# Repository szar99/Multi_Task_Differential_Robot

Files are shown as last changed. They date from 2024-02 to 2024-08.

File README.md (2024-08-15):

# Multi-Task Differential Robot
The Multi-Task Differential Robot project focuses on developing a versatile robot equipped with multiple sensors to perform various tasks. Firstly, it can accurately follow a predefined path by utilizing a line following sensor. Secondly, it features obstacle avoidance functionality, leveraging infrared distance sensors to detect and steer clear of objects within its field of view. When encountering an obstacle, the robot adjusts its direction or maneuvers around it, especially in corner scenarios. Lastly, the robot incorporates object tracking capabilities facilitated by the Pixy2 camera. This enables the robot to track and pursue objects, such as a rolling ball on the ground, enhancing its adaptability and usefulness across different applications.

<p align="center">
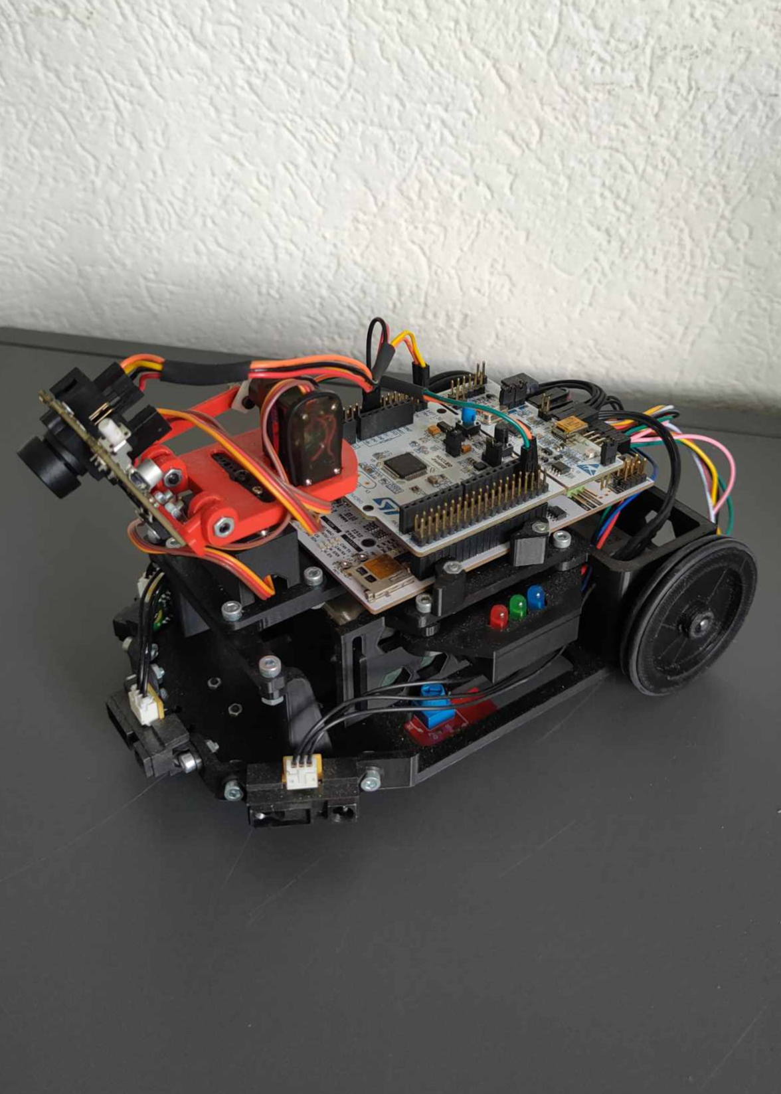
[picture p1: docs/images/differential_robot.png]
Differential robot
     </br>
    <i>Multi-Task Differential Robot</i>
</p>

## Table of Contents
1. [Repository structure](#repository-structure)
2. [Hardware](#hardware)
3. [Prerequisites](#prerequisites)
4. [Kinematics](#kinematics)
5. [Functionalities](#functionalities)
    * [Line follower](#1-line-follower)
    * [Obstacle avoider](#2-obstacle-avoider)
    * [Pixy2 object follower](#3-pixy2-object-follower)
6. [Additions](#additions)
7. [Notes](#notes)

## Repository structure
The ***main.cpp*** file contains all three algorithms. The current algorithm is visible, the rest is commented out.

- ``/docs/cad`` - cad files with division into vechicle frame and gimbal construction for Pixy2. Inside there is a division into different extensions, including print-ready STL files and STEP files. <br>
- ``/docs/documentation`` - folder contains all additional markdown files <br>
- ``/docs/images`` - folder contains all images used in markdown files <br>
- ``/docs/solutions`` - The folder contains the main files of separate three different algorithms. 

## Hardware
Components and sensors employed in the design:
- [Nucleo-F446RE][0]
- 2 x [31:1 Metal Gearmotor 20Dx43L mm 12V CB][1] 
- [SparkFun Line Follower Array][2]
- 4 x [IR distance sensors SHARP 2Y0A21][3] 
- [Pixy2 Cam][4]
- 2 x [Towerpro MG90S servos][5]
- 2 x [Conrad energy NiMH receiver battery packs 6V, 2300mAh][6]
- PES Board
- Jumper wires

All frame parts 3D models are localized in [CAD folder](/docs/cad/)

## Prerequisites
- Mbed Studio
- Libraries:
    - mbed-os 6.17.0
    - eigen
    - pm2_drivers

All the libraries you need are included in the repository. If you use a different design, kinematics, or hardware, you need to change the appropriate variables for the program to run properly. Also, if you are not using a custom PES Board, you need to change pins names that are passed as parameters while objects are defined.

## Running project
In order to run the project you need to import program to Mbed Studio, compile it, and the run on the board. As it was mentioned above, robot has three different functionalities. On the right side of robot there are three diodes, each one of them is sygnalizing the currently used algorithm. Colours are like:
- Pixy follower -> red 
- Obstacle avoider -> green
- Line follower -> blue

After switch on the power source robot will wait for the correct algorithm to be selected by lighting up the LEDs sequentially at five-second intervals. Pressing the **USER** button while the diode of the colour corresponding to the function in question is lit will immediately start the execution of the selected algorithm.

## Kinematics
Comprehensive explanation and description of the kinematics of a differential robot can be found [here](/docs/documentation/kinematics.md).

## Functionalities
As mentioned, the robot has three different functionalities listed below.
### 1. Line follower
The line follower functionality enables the robot to autonomously navigate predefined paths by continuously scanning for contrasting colors or reflective markers with a specialized sensor, making real-time adjustments based on feedback to ensure precise tracking and adherence to the designated route. Details of algorithm you can find [here](/docs/documentation/line_follower.md) <br>
Main file [**Line follower main**](/docs/solutions/Line_follower_main.txt)
### 2. Obstacle avoider
The obstacle avoidance functionality equips the robot with infrared distance sensors to detect objects within its vicinity. When an obstacle is detected, the robot swiftly adjusts its course to avoid collision, either by changing direction or maneuvering around the obstacle. This feature ensures the robot's safe navigation in dynamic environments, preventing potential collisions and ensuring smooth operation. Details of algorithm you can find [here](/docs/documentation/obstacle_avoider.md) <br>
Main file [**Obstacle avoider**](/docs/solutions/Line_follower_main.txt)
### 3. Pixy2 object follower
The Pixy2 object follower functionality allows the robot to seamlessly track and follow designated objects within its view. By leveraging the capabilities of the Pixy2 camera, the robot identifies and locks onto the target object, ensuring precise tracking as it moves. This enables the robot to autonomously follow the object, adjusting its trajectory accordingly for smooth and accurate pursuit. Details of algorithm you can find [here](/docs/documentation/pixy_follower.md) <br>
Main file [**Pixy2 object follower**](/docs/solutions/Line_follower_main.txt)

## Additions
- The files include a map that should be printed on a large scale for the algorithm to run properly: [MAP](docs/Highspeed_2.pdf) 

## Notes:
- Update dependencies after releasing drivers! 

[0]: https://os.mbed.com/platforms/ST-Nucleo-F446RE/
[1]: https://www.pololu.com/product/3487
[2]: https://www.sparkfun.com/products/13582
[3]: https://www.sparkfun.com/products/242
[4]: https://pixycam.com/pixy2/
[5]: https://www.towerpro.com.tw/product/mg90s-3/
[6]: https://www.conrad.ch/de/p/reely-modellbau-akkupack-nimh-6-v-2300-mah-zellen-zahl-5-mignon-aa-side-by-side-jr-buchse-2613252.html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

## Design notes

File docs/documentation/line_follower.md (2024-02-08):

# Line follower
The line follower functionality enables the robot to autonomously navigate along predefined paths by detecting and following lines on the ground. Using a specialized line following sensor, the robot continuously scans the surface for contrasting colors or reflective markers that define the desired path. Real-time adjustments in the robot's movements are made based on the sensor's feedback, ensuring precise tracking and adherence to the designated route.

## Hardware
[Sparkfun Line follower sensor array][1] is used for this functionality.

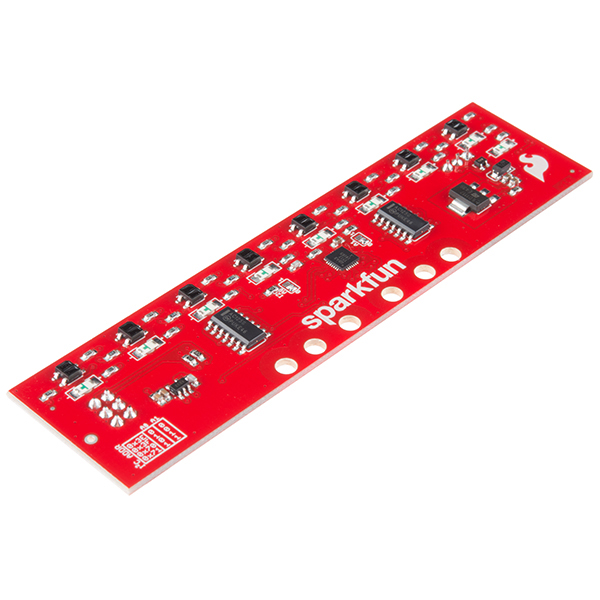
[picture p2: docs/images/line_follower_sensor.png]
Line follower sensor


The sensor incorporates eight diodes for line detection, with each diode's illumination indicating the presence of a line beneath it. Additionally, a calibration knob enables users to adjust detection sensitivity, accommodating variations in substrate and line color shades. More information is available [here][2].

For sensor communication, SPI technology is utilized, which relies on two data pins and a clock (more information [here][3]). To power the sensor, a voltage of around 5V is required.

In the described robot, the following pins are utilized:
- Data **PB_9**
- Clock **PB_8**

**NOTE:** [Nucleo-F446RE pinmap][4] 

## Software
The following is a description of the software used to perform the task in the form of line tracking. 
### Main
The algorithm calculating the appropriate values of wheel speeds is built inside the driver, so from the main file it is necessary to define the appropriate variables and declare the appropriate objects. The software code must contain:
- DC motor object - manual for DC motors can be found here 
<!-- TODO add link -->
- Line follower object - manual for line follower driver can be [here](#line-follower-driver)

The line follower's ``main`` file can be found [here](../solutions/Line_follower_main.txt). The description below refers to this file and contains an explanation of how the algorithm inside is constructed.

#### State machine

1. Initial State (INITIAL):
- In this state, all systems are enabled, and the robot prepares for operation.
- If the robot is moving (determined by the condition `move == true`), it transitions to the FOLLOW state to start following the line.
- If the robot is not moving (determined by the condition `move == false`), it transitions to the SLEEP state to wait for a signal to start moving.

2. Follow State (FOLLOW):
- In this state, the robot actively follows the line using the line-following algorithm.
- The robot's motor speeds are adjusted based on the line-following algorithm's outputs.
- If the robot stops moving (determined by the condition `move == false`), it transitions to the SLEEP state to wait for a signal to start moving again.

3. Sleep State (SLEEP):
- In this state, the robot stops its motors and waits for a signal to start moving.
- If the robot detects movement (determined by the condition `move == true`), it transitions to the FOLLOW state to resume line-following.

#### Possible adjustments
The algorithm is programmed to have the robot move for a specific period after losing the line, and then stop. To achieve this, functionality has been implemented to determine the stopping time for the robot based on a predefined duration. The process unfolds as follows:

1. Time Definition: The parameter `stop_time` defines the duration (in seconds) for which the robot should move after losing the line before coming to a complete stop.

2. Conversion to Iterations: This time is converted into an equivalent number of iterations (`stop_time_iteration`) based on the main task period. For instance, if the main task period is 20 milliseconds and `stop_time` is set to 1 second, then `stop_time_iteration` would be calculated as 1000 ms / 20 ms = 50 iterations.

3. Counter Incrementation: Upon losing the line, a counter (`i`) is incremented. This counter keeps track of the number of iterations since the robot last detected the line.

4. Checking Counter Against Threshold: If the counter (`i`) exceeds the predetermined number of iterations (`stop_time_iteration`), it indicates that the specified time has elapsed since the robot lost the line.

5. Setting the `move` Variable: Once the counter exceeds `stop_time_iteration`, the `move` variable is set to `false`. This action causes the robot to stop moving entirely.

By adjusting the `stop_time` parameter, users can control the duration for which the robot continues to move after losing the line. Increasing `stop_time` extends the movement duration, while decreasing it shortens the interval before the robot comes to a stop.

### Line follower driver
Line follower driver is used to calculate wheel speed based on sensor indications and robot geometry, as well as other settings declared by the user.

#### Constructor
When declaring a function, the following variables must be defined (in **SI** units if applicable):
- SDA pin - used for data transfer in SPI standard
- SCL pin - used for clock synchronization
- bar_dist - distance of diodes from wheel axes
- d_wheel - wheel diameter
- L_wheel - wheelbase
- max_motor_vel_rps - maximum engine speed given in revolutions per second

The remaining values are defined by default, but there is a possibility to change some of the parameters, as described below the description of the internal algorithm operation

**NOTE:** The velocity values provided as input are originally expressed in revolutions per second. However, within the driver, these values are converted into radians per second for calculation purposes. Once the calculation is completed in this unit, it is then converted back into revolutions per second. This conversion allows for the use of a unit directly compatible with the DC motor object.

#### Thread algorithm description
The `followLine` function is a thread task method responsible for controlling the robot to follow a line based on sensor readings.

1. Thread Execution: The `followLine` method runs continuously in a thread loop. It waits for a thread flag to be set before executing, indicating that it should perform its task.

2. Sensor Reading: Inside the loop, the method checks if any LEDs on the sensor bar are active. If any LEDs are active, it calculates the average angle of the detected line segments relative to the robot's orientation. This angle is stored in `m_sensor_bar_avgAngleRad`.

3. Control Calculation:
- The maximum wheel velocity in radians per second (`m_max_wheel_vel_rads`) is calculated based on the maximum wheel velocity (`m_max_wheel_vel`).
- The rotational velocity (`m_robot_coord(1)`) is determined using a control function `ang_cntrl_fcn`, which adjusts the robot's orientation to align with the detected line.
- The translational velocity (`m_robot_coord(0)`) is determined using another control function `vel_cntrl_v2_fcn`, which calculates the robot's forward velocity based on the rotational velocity and geometric parameters.
- The robot's wheel speeds are calculated using the inverse transformation matrix `m_Cwheel2robot`.

4. Wheel Velocity Conversion: The calculated wheel speeds are converted from radians per second to revolutions per second (`m_right_wheel_velocity` and `m_left_wheel_velocity`).

5. Thread Flag Signaling: After completing its task, the method waits for the next iteration by waiting for the thread flag to be set again.

#### Angular velocity controller
The `ang_cntrl_fcn` function is responsible for calculating the angular velocity of the robot based on the detected angle of the line relative to the robot's orientation. This function uses proportional and non-linear control to calculate the velocity based on mentioned angle.

1. Input Parameters:
- `Kp`: Proportional gain parameter for angular control.
- `Kp_nl`: Non-linear gain parameter for angular control.
- `angle`: The angle of the detected line relative to the robot's orientation.

2. Calculation:
- If the angle is positive (`angle > 0`), the function calculates the angular velocity (`retval`) using the formula:
    ```
    retval = Kp * angle + Kp_nl * angle * angle
    ```
    This formula applies proportional control (`Kp * angle`) along with a non-linear correction term (`Kp_nl * angle * angle`).
- If the angle is zero or negative (`angle <= 0`), the function calculates the angular velocity (`retval`) using a similar formula but with a negative sign for the non-linear term:
    ```
    retval = Kp * angle - Kp_nl * angle * angle
    ```
3. Output:
- The function returns the calculated angular velocity (`retval`).

#### Linear velocity controller
The `vel_cntrl_v2_fcn` function calculates the linear velocity of the robot based on its angular velocity and geometric parameters. The function ensures that one of the robot's wheels always turns at maximum velocity while the other adjusts its speed to maintain the desired angular velocity.

1. Input Parameters:
- `wheel_speed_max`: Maximum wheel speed in radians per second.
- `b`: Geometric parameter related to the distance between the wheels .
- `robot_omega`: Angular velocity of the robot.
- `Cwheel2robot`: Transformation matrix from wheel to robot coordinates.

2. Calculation:
- If `robot_omega` is positive, it assigns the maximum wheel speed to the first wheel and calculates the speed for the second wheel by subtracting `2 * b * robot_omega` from the maximum speed.
- If `robot_omega` is negative or zero, it assigns the maximum wheel speed to the second wheel and calculates the speed for the first wheel by adding `2 * b * robot_omega` to the maximum speed.
- The function then calculates the robot's coordinate velocities by multiplying the transformation matrix `Cwheel2robot` by the wheel speeds.
- Finally, it returns the linear velocity of the robot, which corresponds to the velocity along the x-axis in the robot's coordinate system.

3. Output:
- The function returns the calculated linear velocity of the robot.

#### Parametres adjustment
The LineFollower class provides functionality to dynamically adjust key parameters:

1. Proportional Gain (Kp) and Non-linear Gain (Kp_nl):
- Function: `void setRotationalVelocityGain(float Kp, float Kp_nl)`
- Parameters: `Kp` and `Kp_nl`
- Description: These parameters influence the proportional and non-linear correction in the robot's angular velocity control, allowing users to fine-tune the response to deviations from the desired line angle.

2. Maximum Wheel Velocity:
- Function: `void setMaxWheelVelocity(float max_wheel_vel)`
- Parameter: `max_wheel_vel`
- Description: This parameter limits the maximum wheel velocity (argument in rotations per second), indirectly affecting the robot's linear and angular velocities. Users can adjust this limit to optimize performance based on environmental conditions and specific requirements.

<!-- Links: -->
[1]: https://www.sparkfun.com/products/13582
[2]: https://learn.sparkfun.com/tutorials/sparkfun-line-follower-array-hookup-guide
[3]: https://learn.sparkfun.com/tutorials/serial-peripheral-interface-spi/all
[4]: https://os.mbed.com/platforms/ST-Nucleo-F446RE/

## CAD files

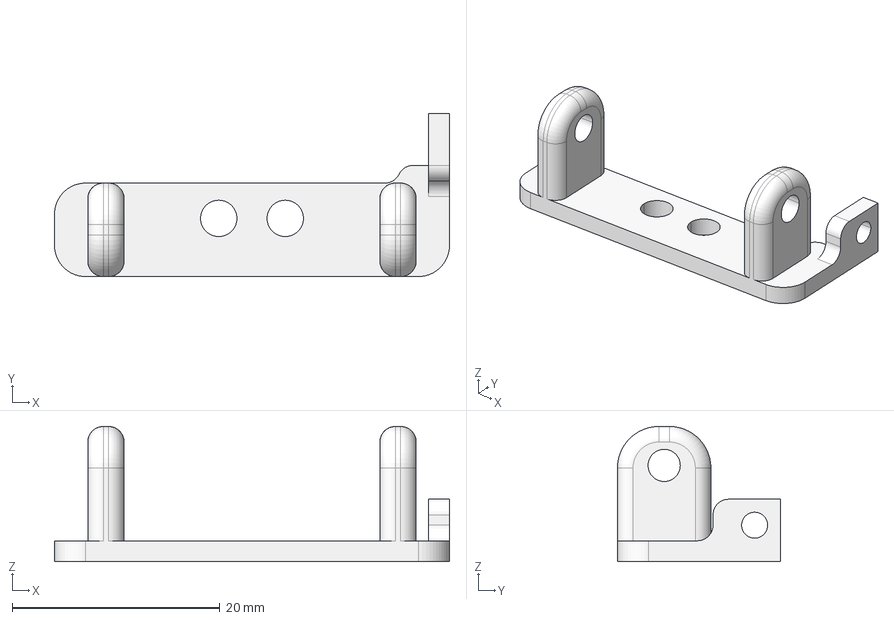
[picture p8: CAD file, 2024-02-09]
docs/cad/pixy2_gimbal/STEP/SDR_mipantiltPixyCam2.stp
38.0 x 15.7 x 13.0 mm

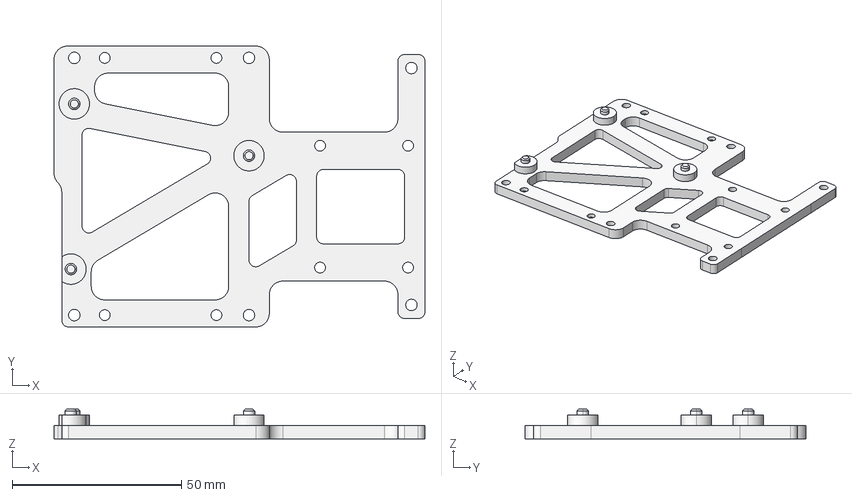
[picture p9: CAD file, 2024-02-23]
docs/cad/robot_frame/STEP/SDR_PCB_BASE_WITH_KNOBS.stp
109.6 x 83.0 x 8.80 mm

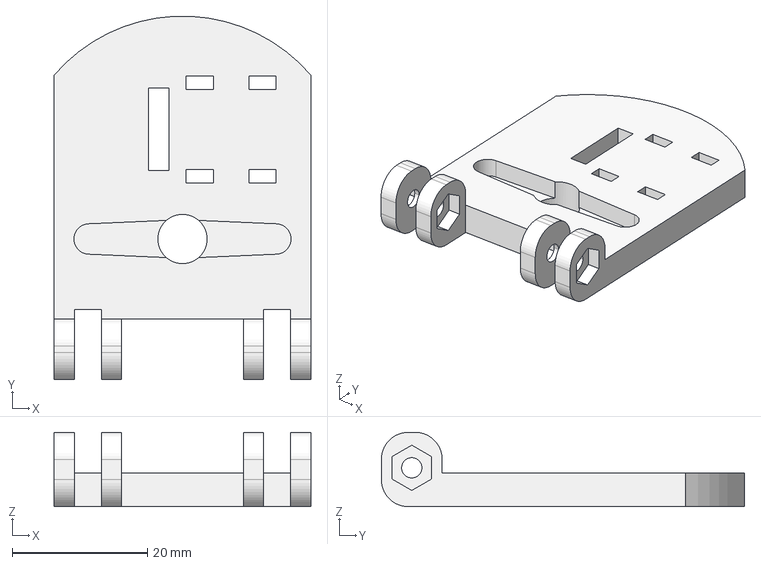
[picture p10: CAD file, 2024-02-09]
docs/cad/pixy2_gimbal/STEP/SDR_mipantiltPixyTilt2.stp
38.0 x 53.7 x 11.0 mm

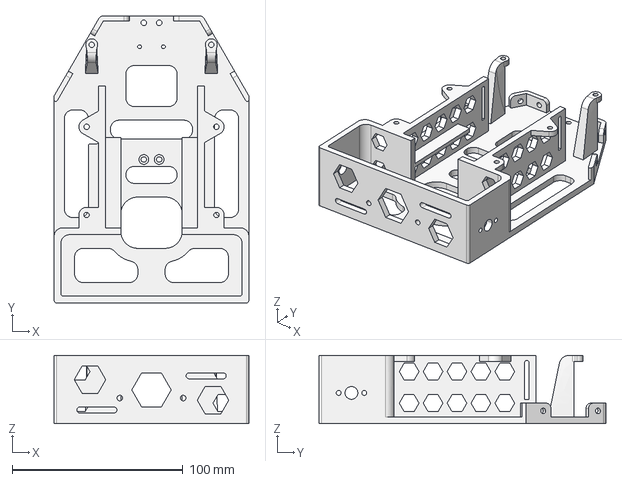
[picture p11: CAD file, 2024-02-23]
docs/cad/robot_frame/STEP/SDR_ROBOT_FRAME.stp
114.0 x 168.0 x 40.0 mm

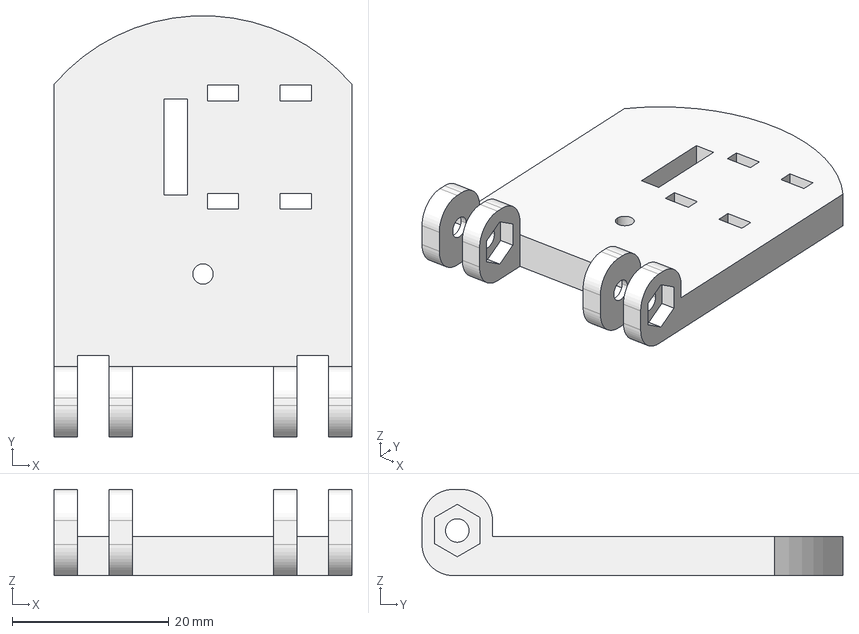
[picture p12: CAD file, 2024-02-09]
docs/cad/pixy2_gimbal/STEP/SDR_mipantiltPixyTilt2_WaveShare.stp
38.0 x 53.7 x 11.0 mm

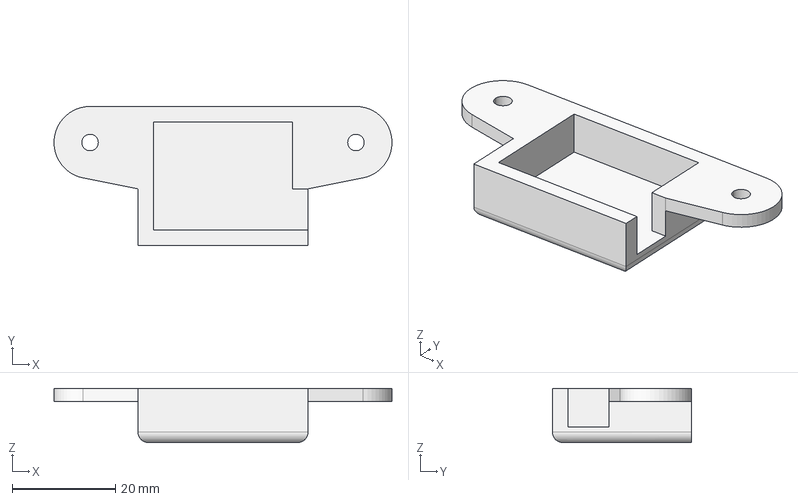
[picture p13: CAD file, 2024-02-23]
docs/cad/robot_frame/STEP/SDR_LED_CASE_DOWN.stp
65.6 x 27.0 x 10.5 mm

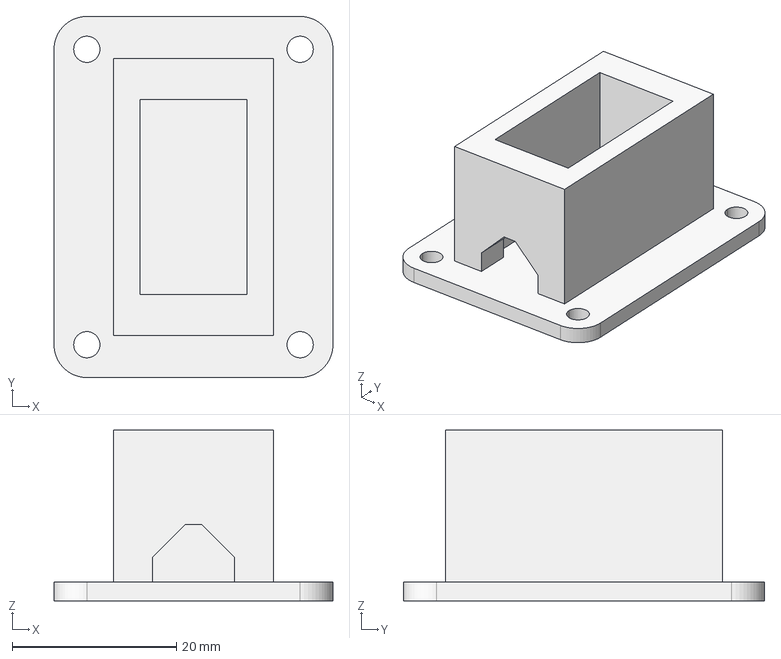
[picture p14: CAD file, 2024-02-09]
docs/cad/pixy2_gimbal/STEP/SDR_mipantiltPixyPan.stp
34.0 x 44.0 x 20.8 mm

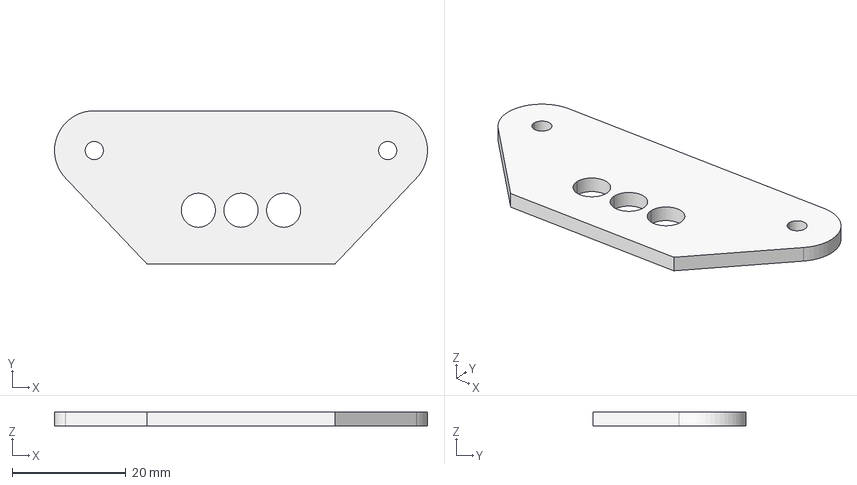
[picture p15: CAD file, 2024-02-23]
docs/cad/robot_frame/STEP/SDR_LED_CASE_TOP.stp
65.6 x 27.0 x 2.50 mm

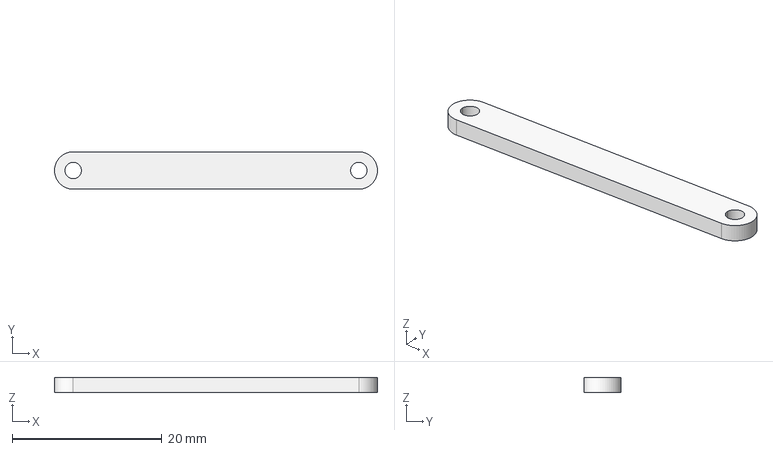
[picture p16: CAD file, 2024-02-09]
docs/cad/pixy2_gimbal/STEP/SDR_mipantiltPixyPush2.stp
43.1 x 5.00 x 2.00 mm

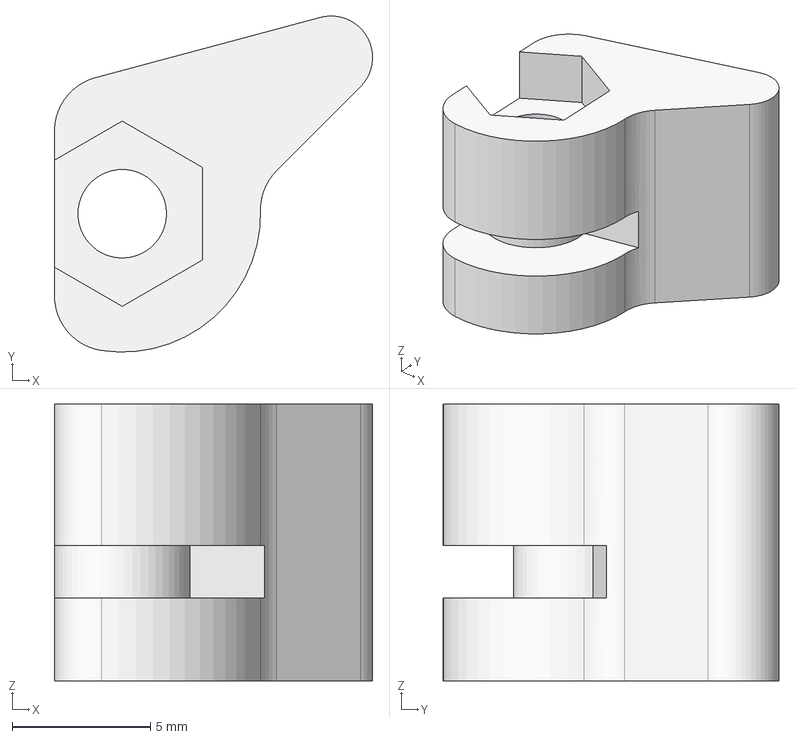
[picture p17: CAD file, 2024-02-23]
docs/cad/robot_frame/STEP/SDR_PCB_MOUNT_KNOB.stp
11.5 x 12.1 x 10.0 mm

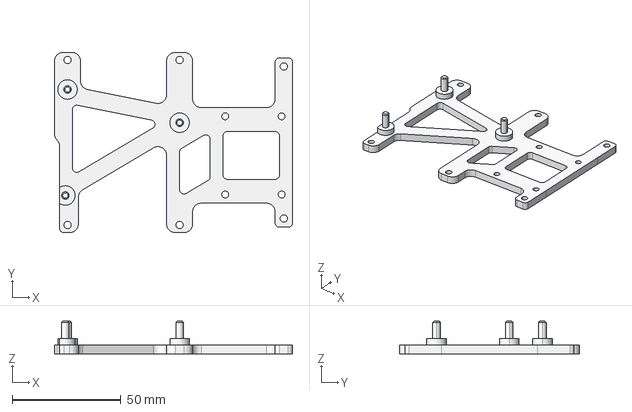
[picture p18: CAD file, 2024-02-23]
docs/cad/robot_frame/STEP/SDR_PCB_BASE_LONG_PINS.stp
109.6 x 83.0 x 15.0 mm

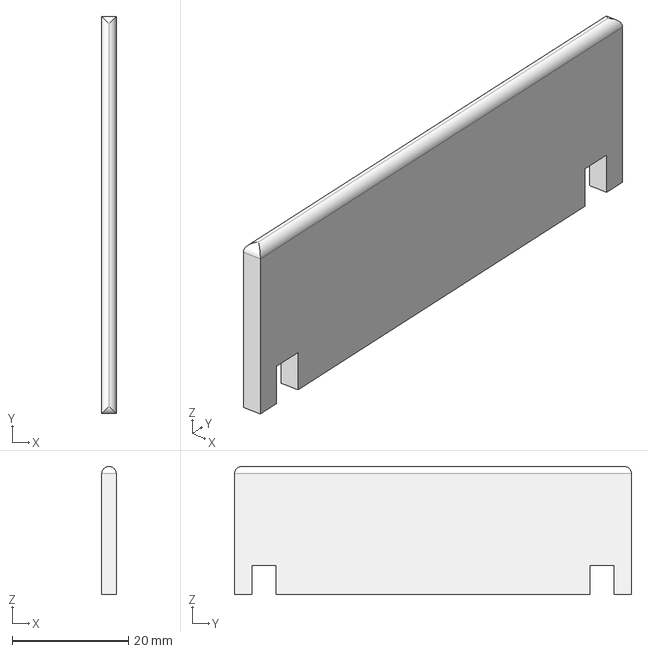
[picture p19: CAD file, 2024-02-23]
docs/cad/robot_frame/STEP/SDR_BATTERY_BLOCK.stp
2.50 x 68.2 x 22.0 mm

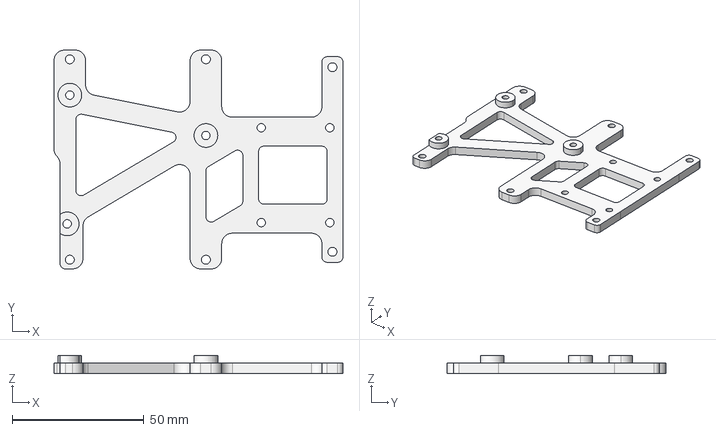
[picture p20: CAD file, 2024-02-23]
docs/cad/robot_frame/STEP/SDR_PCB_BASE_SCREWS.stp
109.6 x 83.0 x 7.00 mm

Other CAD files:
docs/cad/pixy2_gimbal/STEP/SDR_mipantiltPixyTilt2_TowerPro.stp
docs/cad/pixy2_gimbal/STL/SDR_mipantiltPixyCam2.stl
docs/cad/pixy2_gimbal/STL/SDR_mipantiltPixyPan.stl
docs/cad/pixy2_gimbal/STL/SDR_mipantiltPixyPush2.stl
docs/cad/pixy2_gimbal/STL/SDR_mipantiltPixyTilt2.stl
docs/cad/pixy2_gimbal/STL/SDR_mipantiltPixyTilt2_TowerPro.stl
docs/cad/pixy2_gimbal/STL/SDR_mipantiltPixyTilt2_WaveShare.stl
docs/cad/robot_frame/STL/SDR_BATTERY_BLOCK.stl
docs/cad/robot_frame/STL/SDR_LED_CASE_DOWN.stl
docs/cad/robot_frame/STL/SDR_LED_CASE_TOP.stl
docs/cad/robot_frame/STL/SDR_PCB_BASE_LONG_PINS.stl
docs/cad/robot_frame/STL/SDR_PCB_BASE_SCREWS.stl
docs/cad/robot_frame/STL/SDR_PCB_BASE_WITH_KNOBS.stl
docs/cad/robot_frame/STL/SDR_PCB_MOUNT_KNOB.stl
docs/cad/robot_frame/STL/SDR_ROBOT_FRAME.stl

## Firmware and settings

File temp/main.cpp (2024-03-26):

#include <mbed.h>
#include <math.h>

#include "pm2_drivers/DebounceIn.h"
#include "pm2_drivers/Servo.h"
#include "pm2_drivers/EncoderCounter.h"
#include "pm2_drivers/DCMotor.h"
#include "pm2_drivers/UltrasonicSensor.h"
#include "pm2_drivers/IMU.h"
#include "pm2_drivers/SensorBar.h"
#include "pm2_drivers/PESBoardPinMap.h"
#include "eigen/Dense.h"
#include "pm2_drivers/LineFollower.h"
#include "pm2_drivers/PixyCam2.h"

#define M_PI 3.14159265358979323846  // number pi

// logical variable main task
bool do_execute_main_task = false;

// user button on nucleo board
Timer user_button_timer;            
DebounceIn user_button(USER_BUTTON);

// Sensor evaluation function
float ir_sensor_compensation(float _ir_distance_mV);

// Controling functions
// obstacle avoider motion controllers 
float rot_vel_from_radius_fcn(const float& wheel_speed_max, const float& r_wheel, const float& L_wheel ,const float& R_turn);
float turn_angle_limit_fcn(const float& R_turn, const float& r_wheel, const float& L_wheel, const float& angle);
// Pixy object position to velocity 
float pixy_following_x_fcn(const float& x, const float& x_threshold, const float& Kx);
float pixy_following_y_fcn(const float& y, const float& y_t, const float& Ky, const float& y_boundary);
// linear velocity calculation algorithm
float vel_cntrl_v2_fcn(const float& wheel_speed_max, const float& b, const float& robot_omega, const Eigen::Matrix2f& Cwheel2robot);

int main()
{
    // Robot states - three functionalities
    enum RobotState {
        INIT,
        PIXY_FOLLOWER,
        OBST_AVOIDER,
        LINE_FOLLOWER
    } robot_state = RobotState::INIT;

    bool pixy_follower = false;
    bool obst_avoider = false;
    bool line_follower = false;

    // while loop gets executed every main_task_period_ms milliseconds
    const int main_task_period_ms = 30;   // define main task period time in ms
    Timer main_task_timer;
    Timer task_selection_timer;  

    // PIXY FOLLOWER STATE MACHINE WITH 3 STATES:
    // initial - to enable motors
    // follow - to follow object if it is in sight
    // sleep - to do nothing if it is in sight
    enum RobotStatePixyFollower {
        INITIAL_P,
        FOLLOW_P,
        SLEEP_P
    } robot_state_pixy_follower = RobotStatePixyFollower::INITIAL_P;

    // OBSTACLE AVOIDER STATE MACHINE WITH 8 STATES:
    // initial - to enable motors
    // forward - to move forward
    // backward - to move backward and make turn in case of facing obstacle by front sensor
    // backward_corner_left - to move backward and make tight turn in case of facing obstacle by front and left sensor
    // backward_corner_right - to move backward and make tight turn in case of facing obstacle by front and right sensor
    // right - to turn right in case of facing obstacle from left side
    // left - to turn left in case of facing obstacle from right side
    // sleep - to do nothing
    enum RobotStateObstAvoider {
        INITIAL_O,
        FORWARD_O,
        BACKWARD_O,
        BACKWARD_CORNER_LEFT_O,
        BACKWARD_CORNER_RIGHT_O,
        RIGHT_O,
        LEFT_O,
        SLEEP_O,
    } robot_state_obst_avoider = RobotStateObstAvoider::INITIAL_O;

    // LINE FOLLOWER STATE MACHINE WITH 3 STATES:
    // initial - to enable all systems
    // follow - to follow the line
    // sleep - to wait for the signal from the environment (e.g. line detection)
    enum RobotStateLineFollower {
        INITIAL_L,
        FOLLOW_L,
        SLEEP_L,
    } robot_state_line_follower = RobotStateLineFollower::INITIAL_L;

    // led on nucleo board
    DigitalOut user_led(USER_LED);

    DigitalOut led_red(PC_8);
    DigitalOut led_green(PB_2);
    DigitalOut led_blue(PB_12);

    // MOTORS DECLARATIONS
    // Digital out object for enabling motors
    DigitalOut enable_motors(PB_ENABLE_DCMOTORS);

    // In the robot there will be used 31:1 Metal Gearmotor 20Dx44L mm 12V CB
    // Define variables and create DC motor objects
    const float voltage_max = 12.0f;
    const float gear_ratio = 78.125f; 
    const float kn = 180.0f / 12.0f; //motor constant rpm / V
    const float velocity_max = kn * voltage_max / 60.0f; // Max velocity that can be reached
    DCMotor motor_M1(PB_PWM_M1, PB_ENC_A_M1, PB_ENC_B_M1, gear_ratio, kn, voltage_max); //RIGHT
    motor_M1.setEnableMotionPlanner(true);
    motor_M1.setMaxVelocity(motor_M1.getMaxPhysicalVelocity()/2.0f); //right
    DCMotor motor_M2(PB_PWM_M2, PB_ENC_A_M2, PB_ENC_B_M2, gear_ratio, kn, voltage_max); //LEFT
    motor_M2.setEnableMotionPlanner(true);
    motor_M2.setMaxVelocity(motor_M2.getMaxPhysicalVelocity()/2.0f); //left
    const float wheel_speed_max_rads = 2.0f * M_PI * motor_M1.getMaxVelocity(); 

    // ROBOT KINEMATICS AND GEOMETRY
    const float d_wheel = 0.0564f;        // wheel diameter
    const float r_wheel = d_wheel / 2.0f; // wheel radius
    const float L_wheel = 0.13f;         // distance from wheel to wheel
    Eigen::Matrix2f Cwheel2robot; // transform wheel to robot
    //Eigen::Matrix2f Crobot2wheel; // transform robot to wheel
    Cwheel2robot <<  r_wheel / 2.0f   ,  r_wheel / 2.0f   ,
                     r_wheel / L_wheel, -r_wheel / L_wheel;
    //Crobot2wheel << 1.0f / r_wheel,  L_wheel / (2.0f * r_wheel),
    //                1.0f / r_wheel, -L_wheel / (2.0f * r_wheel);
    Eigen::Vector2f robot_coord;  // contains v and w (robot translational and rotational velocities)
    Eigen::Vector2f wheel_speed;  // w1 w2 (wheel speed)
    robot_coord.setZero();
    wheel_speed.setZero();

    const static float b = L_wheel / (2.0f * r_wheel);

    // sensor data evalution
    const float bar_dist = 0.083f;

    // PIXY FOLLOWER OBJECTS AND VARIABLES
    PixyCam2 pixy(PC_10, PC_11, 230400);

    // Evaluation of velocity controller
    float y;
    float x;
    const float y_threshold = 800.0f;
    const float y_boundary = 500.0f;
    const float x_threshold = 500.0f;
    const float Kx = 1.0f / 200.0f;
    const float Ky = 1.0f / 200.0f;
    static float wheel_speed_eval;
    bool isNewMessagePixy = false;

    // OBSTACLE AVOIDER OBJECTS AND VARIABLES
    // condition for state machine that will stop the robot 1 seconds after leaving the line (CAN BE CHANGED)
    bool move = false;
    const static float stop_time = 1.0f; //seconds
    const static int stop_time_iteration = stop_time * 1000 / main_task_period_ms;
    static int i = stop_time_iteration + 1;

    const float R_turn_forward = L_wheel;
    const float R_turn_backward = L_wheel;
    const float R_turn_corner_backward = L_wheel / 2.0f;  

    const float alfa_backward = 90.0f;
    const float alfa_backward_corner = 135.0f;
    const float wheel_rounds_backward = turn_angle_limit_fcn(R_turn_backward, r_wheel, L_wheel, alfa_backward);
    const float wheel_rounds_backward_corner = turn_angle_limit_fcn(R_turn_corner_backward, r_wheel, L_wheel, alfa_backward_corner);

    static float init_rotation;
    static float actual_rotation;
    static bool isFirst = false;

    //IR range sensors:
    AnalogIn ir_analog_in_left(PC_2);
    AnalogIn ir_analog_in_right(PC_5);
    AnalogIn ir_analog_in_front(PC_3);
    AnalogIn ir_analog_in_back(PB_1);

    static float ir_distance_left_cm = 0.0f;
    static float ir_distance_right_cm = 0.0f;
    static float ir_distance_front_cm = 0.0f;
    static float ir_distance_back_cm = 0.0f;

    // Distance threshold for sensors
    const float threshold = 13.0f;

    // LINE FOLLOWER OBJECTS AND VARIABLES
    LineFollower lineFollower(PB_9, PB_8, bar_dist, d_wheel, L_wheel, velocity_max/2.0f);

    // MAIN THREAD FUNCTION
    // Timer to measure task execution time
    main_task_timer.start();

    while (true) {
        main_task_timer.reset();
        task_selection_timer.start();
        
        switch (robot_state) {
            case RobotState::INIT: {
                int task_selection_time_ms = std::chrono::duration_cast<std::chrono::milliseconds>(task_selection_timer.elapsed_time()).count();
                if (task_selection_time_ms >= 1000 && task_selection_time_ms < 5000){
                    pixy_follower = true;
                    led_red = 1;
                }
                else if ((task_selection_time_ms >= 5000 && task_selection_time_ms < 10000)) {
                    pixy_follower = false;
                    obst_avoider = true;
                    led_red = 0;
                    led_green = 1;
                }
                else if ((task_selection_time_ms >= 10000 && task_selection_time_ms < 15000)) {
                    obst_avoider = false;
                    line_follower = true;
                    led_green = 0;
                    led_blue = 1;
                } 
                else if (task_selection_time_ms >= 15000) {
                    led_blue = 0;
                    line_follower = false;
                    task_selection_timer.reset();
                }
                
                if (pixy_follower && user_button == 0){
                    robot_state = PIXY_FOLLOWER;
                }
                else if (obst_avoider && user_button == 0) {
                    robot_state = OBST_AVOIDER;
                }
                else if (line_follower && user_button == 0) {
                    robot_state = LINE_FOLLOWER;
                } else {
                    break;
                }

                break;
            }
            case RobotState::PIXY_FOLLOWER: {
                printf("PIXYFOLLOWER \n");
                y = (float)pixy.getTiltCommand();
                x = (float)pixy.getPanCommand();
                // state machine
                switch (robot_state_pixy_follower) {
                    case RobotStatePixyFollower::INITIAL_P:
                        enable_motors = 1;
                        pixy.followerEnable(true);
                        isNewMessagePixy = pixy.checkForNewMessage();
                        if (isNewMessagePixy == true) {
                            robot_state_pixy_follower = RobotStatePixyFollower::FOLLOW_P;
                        } else {
                            robot_state_pixy_follower = RobotStatePixyFollower::SLEEP_P;
                        }
                        break;

                    case RobotStatePixyFollower::FOLLOW_P:
                        robot_coord(1) = pixy_following_x_fcn(x, x_threshold, Kx);
                        wheel_speed_eval = pixy_following_y_fcn(y, y_threshold, Ky, y_boundary);
                        robot_coord(0) = vel_cntrl_v2_fcn(wheel_speed_eval, b, robot_coord(1), Cwheel2robot);
                        // transform robot coordinates to wheel speed
                        wheel_speed = Cwheel2robot.inverse() * robot_coord;

                        motor_M1.setVelocity(wheel_speed(0) / (2.0f * M_PI));
                        motor_M2.setVelocity(wheel_speed(1) / (2.0f * M_PI));
                        isNewMessagePixy = pixy.checkForNewMessage();

                        if (isNewMessagePixy == false) {
                            robot_state_pixy_follower = RobotStatePixyFollower::SLEEP_P;
                        }
                        break;
                    case RobotStatePixyFollower::SLEEP_P:
                        motor_M1.setVelocity(0.0f);
                        motor_M2.setVelocity(0.0f);
                        pixy.followerEnable(false);
                        pixy.setServos(500, 500);
                        isNewMessagePixy = pixy.checkForNewMessage();

                        if (isNewMessagePixy == true) {
                            pixy.followerEnable(true);
                            robot_state_pixy_follower = RobotStatePixyFollower::FOLLOW_P;
                        }
                        break;
                    default:
                        break; // do nothing
                }
                break;
            }
            case RobotState::OBST_AVOIDER: {
                printf("OBSTACLEAVOIDER \n");
                //IR sensors distances
                ir_distance_left_cm = ir_sensor_compensation(1.0e3f * ir_analog_in_left.read() * 3.3f);
                ir_distance_right_cm = ir_sensor_compensation(1.0e3f * ir_analog_in_right.read() * 3.3f);
                ir_distance_front_cm = ir_sensor_compensation(1.0e3f * ir_analog_in_front.read() * 3.3f);
                ir_distance_back_cm = ir_sensor_compensation(1.0e3f * ir_analog_in_back.read() * 3.3f);

                // transform robot coordinates to wheel speed
                wheel_speed = Cwheel2robot.inverse() * robot_coord;
                
                switch (robot_state_obst_avoider) {
                    case RobotStateObstAvoider::INITIAL_O:
                        enable_motors = 1;
                        robot_state_obst_avoider = RobotStateObstAvoider::FORWARD_O;
                        break;

                    case RobotStateObstAvoider::FORWARD_O:
                        robot_coord(1) = 0;
                        robot_coord(0) = vel_cntrl_v2_fcn(wheel_speed_max_rads, b, robot_coord(1), Cwheel2robot);
                        wheel_speed = Cwheel2robot.inverse() * robot_coord;

                        motor_M1.setVelocity(wheel_speed(0) / (2.0f * M_PI));
                        motor_M2.setVelocity(wheel_speed(1) / (2.0f * M_PI));
                        
                        if (ir_distance_front_cm < threshold & ir_distance_right_cm > threshold & ir_distance_left_cm > threshold) {
                            isFirst = true;
                            robot_state_obst_avoider = RobotStateObstAvoider::BACKWARD_O;
                        }
                        else if (ir_distance_left_cm < threshold) {
                            robot_state_obst_avoider = RobotStateObstAvoider::RIGHT_O;
                        }
                        else if (ir_distance_right_cm < threshold) {
                            robot_state_obst_avoider = RobotStateObstAvoider::LEFT_O;
                        }
                        else if (ir_distance_front_cm < threshold & ir_distance_right_cm < threshold) {
                            isFirst = true;
                            robot_state_obst_avoider = RobotStateObstAvoider::BACKWARD_CORNER_RIGHT_O;
                        }
                        else if (ir_distance_front_cm < threshold & ir_distance_left_cm < threshold) {
                            isFirst = true;
                            robot_state_obst_avoider = RobotStateObstAvoider::BACKWARD_CORNER_LEFT_O;
                        }
                        break;

                    case RobotStateObstAvoider::BACKWARD_O: // add routine to turn with bigger radius and go forward after 45 degrees turn
                        if (isFirst) {
                            if (ir_distance_left_cm < ir_distance_right_cm) {
                                init_rotation = motor_M1.getRotation();
                                actual_rotation = motor_M1.getRotation();
                                robot_coord(1) = - rot_vel_from_radius_fcn(wheel_speed_max_rads, r_wheel, L_wheel, R_turn_backward);
                            }
                            else {
                                init_rotation = motor_M2.getRotation();
                                actual_rotation = motor_M2.getRotation();
                                robot_coord(1) = rot_vel_from_radius_fcn(wheel_speed_max_rads, r_wheel, L_wheel, R_turn_backward);
                            } 
                        } 
                        else {
                            if (ir_distance_left_cm < ir_distance_right_cm) {
                                actual_rotation = motor_M1.getRotation();
                            }
                            else {
                                actual_rotation = motor_M2.getRotation();
                            }
                        }
                        isFirst = false;
                        robot_coord(0) = vel_cntrl_v2_fcn(-wheel_speed_max_rads, b, robot_coord(1), Cwheel2robot);
                        wheel_speed = Cwheel2robot.inverse() * robot_coord;
                        motor_M1.setVelocity(wheel_speed(0) / (2.0f * M_PI));
                        motor_M2.setVelocity(wheel_speed(1) / (2.0f * M_PI));
                        

                        if (ir_distance_back_cm < threshold | actual_rotation < (init_rotation - wheel_rounds_backward)) {
                            init_rotation = 0.0f;
                            actual_rotation = 0.0f;
                            robot_state_obst_avoider = RobotStateObstAvoider::FORWARD_O;
                        }
                        break;

                    case RobotStateObstAvoider::RIGHT_O:
                        robot_coord(1) = - rot_vel_from_radius_fcn(wheel_speed_max_rads, r_wheel, L_wheel, R_turn_forward);
                        robot_coord(0) = vel_cntrl_v2_fcn(wheel_speed_max_rads, b, robot_coord(1), Cwheel2robot);
                        motor_M1.setVelocity(wheel_speed(0) / (2.0f * M_PI));
                        motor_M2.setVelocity(wheel_speed(1) / (2.0f * M_PI));

                        if  (ir_distance_left_cm > threshold) {
                            robot_state_obst_avoider = RobotStateObstAvoider::FORWARD_O;
                        }
                        else if (ir_distance_front_cm < threshold & ir_distance_left_cm < threshold) {
                            isFirst = true;
                            robot_state_obst_avoider = RobotStateObstAvoider::BACKWARD_CORNER_LEFT_O;
                        }
                        break;

                    case RobotStateObstAvoider::LEFT_O:
                        robot_coord(1) = rot_vel_from_radius_fcn(wheel_speed_max_rads, r_wheel, L_wheel, R_turn_forward);
                        robot_coord(0) = vel_cntrl_v2_fcn(wheel_speed_max_rads, b, robot_coord(1), Cwheel2robot);
                        motor_M1.setVelocity(wheel_speed(0) / (2.0f * M_PI));
                        motor_M2.setVelocity(wheel_speed(1) / (2.0f * M_PI));

                        if  (ir_distance_right_cm > threshold) {
                            robot_state_obst_avoider = RobotStateObstAvoider::FORWARD_O;
                        }
                        else if (ir_distance_front_cm < threshold & ir_distance_right_cm < threshold) {
                            isFirst = true;
                            robot_state_obst_avoider = RobotStateObstAvoider::BACKWARD_CORNER_RIGHT_O;
                        }
                        break;

                    // Write routine to turn around one of the wheel for both cases, add condition then after turning 90 degrees go forward
                    case RobotStateObstAvoider::BACKWARD_CORNER_LEFT_O:
                        if (isFirst) {
                            init_rotation = motor_M1.getRotation();
                            actual_rotation = motor_M1.getRotation();
                        } 
                        else {
                            actual_rotation = motor_M1.getRotation();
                        }
                        isFirst = false; 
                        robot_coord(1) = - rot_vel_from_radius_fcn(wheel_speed_max_rads, r_wheel, L_wheel, R_turn_corner_backward);
                        robot_coord(0) = vel_cntrl_v2_fcn(0.0f, b, robot_coord(1), Cwheel2robot);
                        motor_M1.setVelocity(wheel_speed(0) / (2.0f * M_PI));
                        motor_M2.setVelocity(wheel_speed(1) / (2.0f * M_PI));

                        if  (ir_distance_back_cm < threshold | actual_rotation < (init_rotation - wheel_rounds_backward_corner)) {
                            init_rotation = 0.0f;
                            actual_rotation = 0.0f;
                            robot_state_obst_avoider = RobotStateObstAvoider::FORWARD_O;
                        }
                        break;

                    case RobotStateObstAvoider::BACKWARD_CORNER_RIGHT_O:
                        if (isFirst) {
                            init_rotation = motor_M2.getRotation();
                            actual_rotation = motor_M2.getRotation();
                        } 
                        else {
                            actual_rotation = motor_M2.getRotation();
                        }
                        isFirst = false;
                        robot_coord(1) = rot_vel_from_radius_fcn(wheel_speed_max_rads, r_wheel, L_wheel, R_turn_corner_backward);
                        robot_coord(0) = vel_cntrl_v2_fcn(0.0f, b, robot_coord(1), Cwheel2robot);
                        motor_M1.setVelocity(wheel_speed(0) / (2.0f * M_PI));
                        motor_M2.setVelocity(wheel_speed(1) / (2.0f * M_PI));

                        if  (ir_distance_back_cm < threshold | actual_rotation < (init_rotation - wheel_rounds_backward_corner)) {
                            init_rotation = 0.0f;
                            actual_rotation = 0.0f;
                            robot_state_obst_avoider = RobotStateObstAvoider::FORWARD_O;
                        }
                        break;

                    default:
                        break; // do nothing
                }
                break;
            }
            case RobotState::LINE_FOLLOWER: {
                printf("LINEFOLLOWER \n");
                // line detection checking
                if (lineFollower.isLedActive()) {
                    i = 0;
                } else {
                    i += 1;
                }

                // robot stop condition checking
                if (i > stop_time_iteration) {
                    move = false;
                } else {
                    move = true;
                }
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

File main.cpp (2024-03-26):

#include "mbed.h"

// pes board pin map
#include "pm2_drivers/PESBoardPinMap.h"

// drivers
#include "pm2_drivers/DebounceIn.h"
#include "pm2_drivers/Servo.h"
#include "pm2_drivers/EncoderCounter.h"
#include "pm2_drivers/DCMotor.h"
#include "pm2_drivers/UltrasonicSensor.h"
#include "pm2_drivers/IMU.h"
#include "pm2_drivers/SensorBar.h"
#include "pm2_drivers/PESBoardPinMap.h"
#include "eigen/Dense.h"
#include "pm2_drivers/LineFollower.h"
#include "pm2_drivers/PixyCam2.h"

#define M_PI 3.14159265358979323846  // number pi

bool do_execute_main_task = false; // this variable will be toggled via the user button (blue button) and
                                   // decides whether to execute the main task or not
bool do_reset_all_once = false;    // this variable is used to reset certain variables and objects and
                                   // shows how you can run a code segment only once
// while loop gets executed every main_task_period_ms milliseconds, this is a
// simple approach to repeatedly execute main
const int main_task_period_ms = 20; // define main task period time in ms e.g. 20 ms, there for
                                    // the main task will run 50 times per second

// objects for user button (blue button) handling on nucleo board
DebounceIn user_button(USER_BUTTON); // create DebounceIn object to evaluate the user button
                                     // falling and rising edge
void toggle_do_execute_main_fcn();   // custom function which is getting executed when user
                                     // button gets pressed, definition below
//float iir_filter(float u_k);         // function for implementing low pass filter 

// main runs as an own thread
int main()
{
    // attach button fall function address to user button object, button has a pull-up resistor
    user_button.fall(&toggle_do_execute_main_fcn);

    Timer main_task_timer;              // create Timer object which we use to run the main task
                                        // every main_task_period_ms
    Timer timer;

    // led on nucleo board
    DigitalOut user_led(USER_LED);
 
    // start timer
    main_task_timer.start();
    timer.start();

    // PIXY FOLLOWER OBJECTS AND VARIABLES
    PixyCam2 pixy(PC_10, PC_11, 230400);

    // this loop will run forever
    while (true) {
        main_task_timer.reset();

        if (do_execute_main_task) {
            pixy.followerEnable(true);
            printf("Hello \n");
        } else {
            // the following code block gets executed only once
            if (do_reset_all_once) {
                do_reset_all_once = false;

            }
        }
        // toggling the user led
        user_led = !user_led;

        
        int main_task_elapsed_time_ms = std::chrono::duration_cast<std::chrono::milliseconds>(main_task_timer.elapsed_time()).count();
        thread_sleep_for(main_task_period_ms - main_task_elapsed_time_ms);
    }
}

void toggle_do_execute_main_fcn()
{
    // toggle do_execute_main_task if the button was pressed
    do_execute_main_task = !do_execute_main_task;
    // set do_reset_all_once to true if do_execute_main_task changed from false to true
    if (do_execute_main_task)
        do_reset_all_once = true;
}

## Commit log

2024-02-08 Kinematics and line follower driver done. Readme file with overview of how this repo should look like
2024-02-09 Pixy2 gimbal 3d parts added, minor changes in kinematics and main
    [SDR_mipantiltPixyCam2.stl, SDR_mipantiltPixyCam2.stp, SDR_mipantiltPixyPan.stl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]
2024-02-15 Kinematics documentation updated.
2024-02-23 Added STEP and STL files to the CAD folder, updated README and documentation
    [SDR_BATTERY_BLOCK.stl, SDR_BATTERY_BLOCK.stp, SDR_LED_CASE_DOWN.stl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]
